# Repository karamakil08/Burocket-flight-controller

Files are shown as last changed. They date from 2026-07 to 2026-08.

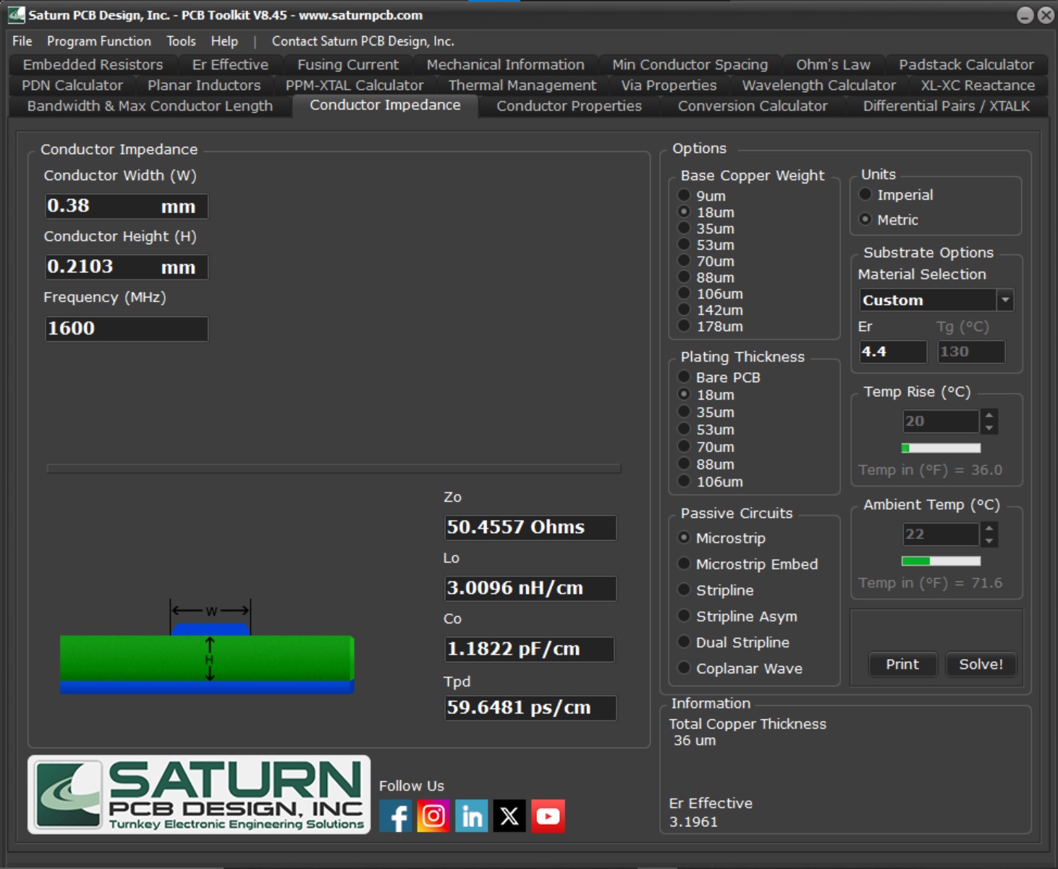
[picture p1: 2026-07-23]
docs/Impedance matching calculations/GPS Mircostrip waveguide 50 ohm impedance.jpg

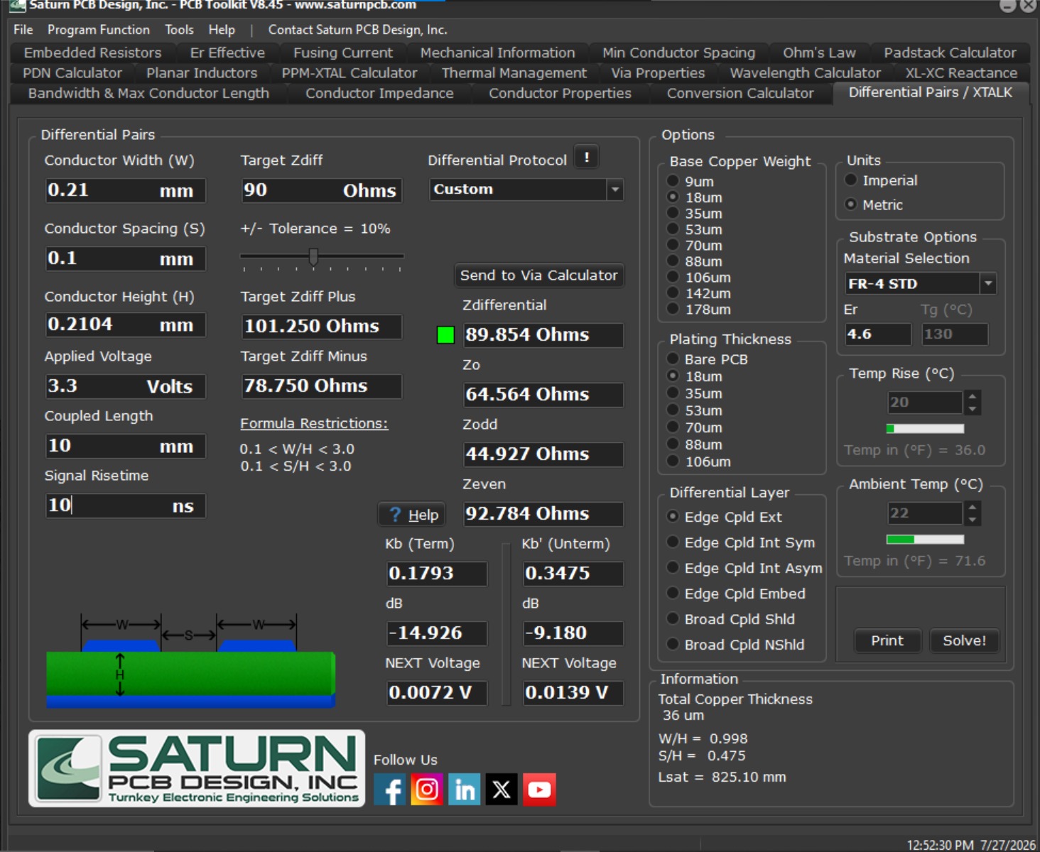
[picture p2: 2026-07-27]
docs/Impedance matching calculations/USB-c Differential pair 90 ohm impedance.jpg

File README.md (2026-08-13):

# Burocket Flight Controller

This is a flight controller built around the STM32F405 MCU for model rocket applications designed to perform altitude, gyro, and acceleration measurements, fire pyrotechnics, and save flight data safely.

## Component Selection

The components selected for this project were chosen according to various measures:
* Application requirement
* Ease of supply
* Price
* Performance
* Footprint area

## Hardware Subsystems

Detailed documentation for each subsystem can be found below:

* [MCU](docs/MCU.md)
* [Sensors](docs/Sensors.md)
* [POWER](docs/POWER.md)
* [Relays](docs/Relays.md)
* [LoRa](docs/LoRa.md)
* [USB-C](docs/USB-C.md)
* [Flash Memory](docs/Flash_memory.md)
* [SD-Card](docs/SD-card.md)

## Pin Distribution & Firmware

You can find the STMCubeMX pin distribution and firmware source files here:
* 🔗 [Firmware Directory](https://github.com/karamakil08/Burocket-flight-controller/tree/main/Firmware)

## Documentation & Resources

* 🔗 [Datasheets](https://github.com/karamakil08/Burocket-flight-controller/tree/main/docs/Datasheets)
* 🔗 [Application Notes](https://github.com/karamakil08/Burocket-flight-controller/tree/main/docs/App%20notes)
* 🔗 [Additional Useful Resources](https://github.com/karamakil08/Burocket-flight-controller/blob/main/docs/App%20notes/Links%20to%20additional%20resources%20I%20found%20useful.md)

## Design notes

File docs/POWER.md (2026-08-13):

# Power Subsystem

The power delivery network is designed to ensure continuous, clean power to all logic and sensor systems, with fail-safes for ground testing and flight operations.

## Power Sources & Multiplexing

The system operates from two primary power sources:
1.  **Flight Battery:** A 2S LiPo battery (nominally 7.4V - 8.4V).
2.  **USB-C VBUS:** 5V provided via the USB interface for ground configuration and data retrieval.

**Buck Conversion & 5V Bus:**
The 2S battery voltage is stepped down to 5V using a dedicated buck converter. This 5V bus is used to power higher-voltage peripherals, including the LoRa telemetry module.

**Power Muxing (TPS2121RUXR):**
To safely manage power when both the battery and USB are connected, the system uses a **TPS2121RUXR** priority power multiplexer. This IC automatically and seamlessly switches between the 5V buck output and the USB-C VBUS. It prevents back-powering into the USB host and eliminates voltage droops or system resets when plugging or unplugging the USB cable on the launch pad.

## 3.3V Regulation

**LDO Regulator:** TPS7A4701
The 5V multiplexed output is stepped down to 3.3V using the **TPS7A4701** Low-Dropout (LDO) regulator. 
*   **Properties:** The TPS7A4701 is an ultra-low-noise ($4.1 \text{ }\mu V_{RMS}$), high-PSRR linear regulator capable of outputting up to 1A. 
*   **Application:** While highly capable, this is an instrumentation-grade regulator. Its extreme noise rejection ensures that the high-resolution ADCs on the MS5611 barometer and ICM IMUs have a perfectly stable voltage reference, minimizing noise floor in the telemetry data.

## Power Monitoring & Current Sensing

To monitor system health, power consumption, and battery state, a high-precision current sensing architecture is implemented on the main power rails.

**Current Sensor:** INA226
The **INA226** is a bidirectional current and power monitor with an I2C interface. It measures both the shunt voltage drop and the bus supply voltage, allowing the flight computer to log real-time power consumption and detect potential shorts or brown-out conditions before they cause a critical failure.

**Shunt Resistor:** WSLP12065L000FEA
*   **Properties:** $5\text{ m}\Omega$, 1% tolerance, 1W rating in a 1206 package.
*   **Performance:** Using a $5\text{ m}\Omega$ shunt with the INA226 (which has a maximum shunt voltage reading of $81.92\text{ mV}$) allows the system to measure current peaks up to $\sim 16.38\text{ A}$ before the ADC saturates ($I = \frac{81.92\text{ mV}}{5\text{ m}\Omega}$). The 1W power rating ensures the resistor can comfortably handle high current spikes (up to $14.1\text{ A}$ continuous) without thermal degradation or desoldering under load.

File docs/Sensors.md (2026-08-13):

# Sensors Subsystem

The sensor suite on this flight controller is designed to provide high-resolution, high-speed telemetry for orientation, altitude detection, and recovery operations. 

## Barometric Pressure & Temperature

**Sensor:** MS5611
The MS5611 is an industry-standard, high-reliability altimeter utilized heavily in aerospace and drone applications. It features a 24-bit ADC providing a resolution of up to 10 cm, which is critical for accurate apogee detection and precise pyrotechnic deployment. It was selected due to its proven track record in flight computers, overall abundance in the supply chain, and ease of integration.

## Inertial Measurement Units (IMU)

**Primary IMU:** ICM-42688-P
The ICM-42688-P is a premium 6-axis MEMS motion tracking device that combines a 3-axis gyroscope and a 3-axis accelerometer. It features exceptionally low noise and high sensitivity, providing the real-time orientation and angular velocity data required for flight stabilization and trajectory tracking. 

**High-G Accelerometer:** ADXL375
Standard IMUs typically saturate at around **16g**, which is easily exceeded during the boost phase or ejection shock of a high-powered model rocket. The ADXL375 is an additional 3-axis accelerometer capable of measuring up to **200g**. This ensures continuous data logging and flight profiling even when the ICM-42688-P's accelerometer is saturated.

**Design Consideration & Alternative:**
Using both the ICM-42688-P and ADXL375 introduces a physical challenge: if the sensor axes are not perfectly aligned on the PCB, a rotation matrix must be applied in software to normalize the data vectors. While solvable in firmware, this adds computational overhead and complexity. 
* *Alternative:* Future revisions may consider the **ICM-45686**, which features a **32g** acceleration limit. Depending on the motor profile, this higher limit might prevent saturation entirely, allowing the removal of the ADXL375 and bypassing the axes alignment complications entirely.

## GPS / GNSS Receiver

**Sensor:** MAX-M10N
The MAX-M10N by u-blox is a highly sensitive, ultra-low-power GNSS receiver module. It tracks multiple constellations concurrently (GPS, Galileo, GLONASS, and BeiDou), providing rapid lock times and high positional accuracy. This is the primary system utilized for post-flight ground tracking and rocket recovery.

## SPI Bus Signal Integrity & Safety

Communication with the primary sensors is handled via the SPI bus, which has been designed with strict signal integrity and fail-safes in mind:

* **Series Termination Resistors:** High-speed SPI lines are susceptible to ringing and voltage overshoots. Series resistors are placed on the bus lines to match the impedance of the traces. To function correctly, these resistors are placed as physically close to the driving device as possible (near the MCU for MOSI and SCK; near the sensors for MISO).
* **Slave Select (SS) Pull-Ups:** Dedicated pull-up resistors are integrated on all SS lines. This hardware-level safeguard keeps the pins at a logical HIGH state during system startup, resets, or when the MCU is unconfigured. This guarantees that the peripheral chips do not accidentally activate, listen to floating lines, or corrupt the shared bus before the firmware actively takes control.

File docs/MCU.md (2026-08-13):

# MCU Subsystem

## Clock Configuration

The system is driven by a 25 MHz High-Speed External (HSE) oscillator. A series damping resistor is often recommended to limit the crystal drive level, but it was deemed non-mandatory and excluded from this design.

The load capacitors for the oscillator were calculated using the standard formula:

$$C_1 = C_2 = 2 \times (C_L - C_S)$$

Where:
*   **$C_L$ (Load Capacitance):** 10 pF (based on the [ECS-250-10-36Q-ES-TR](https://www.mouser.com/ProductDetail/ECS/ECS-250-10-36Q-ES-TR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) specification)
*   **$C_S$ (Stray Capacitance):** Estimated at 5 pF for this PCB layout

$$C_1 = C_2 = 2 \times (10\text{ pF} - 5\text{ pF}) = 10\text{ pF}$$

Based on this calculation, 10 pF capacitors were selected for both $C_1$ and $C_2$.

## User Interface & Controls

*   **Status Indicators:** The board features two indicator LEDs (one Red, one Blue) for system state feedback.
*   **Hardware Reset:** A dedicated push button is routed to the NRST pin to allow manual system resets.
*   **Boot Configuration:** An SPDT (Single Pole Double Throw) switch is connected to the BOOT pin, allowing the user to physically toggle between boot modes.

## Power & Debugging

*   **Decoupling:** Power delivery is stabilized across the MCU utilizing X7R dielectric capacitors, selected for their high performance and temperature stability in flight environments.
*   **Programming Interface:** A Serial Wire Debug (SWD) interface is exposed for programming and debugging. This interface includes a Serial Wire Output (SWO) pin connection to enable real-time trace logging.

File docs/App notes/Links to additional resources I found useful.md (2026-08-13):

# Useful Technical References & Resources

## STM32 Configuration
- Configuring a pin as open-drain output with EXTI:  
  [STM32 Community Thread](https://community.st.com/stm32-mcus-products-25/pin-as-an-open-drain-output-and-exti-at-the-same-time-stm32f030-58373)

## Passive Component Selection Tools
- **Samsung Capacitor Library**:  
  [MLCC & EC Tool](https://weblib.samsungsem.com/mlcc/mlcc-ec.do)  
- **Murata Passive Components**:  
  [SimSurfing Tool](https://www.murata.com/tool/simsurfing)

## Ferrite Beads
- [Short Overview](https://shorturl.at/rvSlJ)  
- [Video: How Ferrite Beads Work](https://www.youtube.com/watch?v=HaLMjVkKYMw)  
- [Altium: Everything You Need to Know](https://resources.altium.com/p/everything-you-need-to-know-about-ferrite-beads)  
- [Altium: How to Choose the Right One](https://resources.altium.com/p/how-do-ferrite-beads-work-and-how-do-you-choose-right-one)  
- [Altium: Three Frequency Ranges for Usage](https://resources.altium.com/p/three-frequency-ranges-ferrite-bead-usage)

## Buck Converters
- [Switching Regulator PCB Design - Phil's Lab](https://www.youtube.com/watch?v=AmfLhT5SntE)  
- [Switching Regulator Component Selection & Sizing - Phil's Lab](https://www.youtube.com/watch?v=FqT_Ofd54fo)  
- [Switching Power Supply PCB Layout Seminar](https://www.youtube.com/watch?v=gq-0ZpcGm8E)  
- [How to Select the Right Inductor for a Buck Converter](https://www.youtube.com/watch?v=ro_ZoAuNZG4)  
- [TI Webench Power Designer](https://webench.ti.com/power-designer/)

## Differential Pairs (USB)
- [Differential Pairs - PCB Design Basics - Phil's Lab](https://www.youtube.com/watch?v=xwrdvhm4vgw)  
- [What your Differential Pairs Wish You Knew with Rick Hartley](https://www.youtube.com/watch?v=QG0Apol-oj0)

## Controlled Impedance
- [Controlled Impedance Explained](https://www.youtube.com/watch?v=aNYmOIMt7CY)

## ESD Protection
- [ESD Protection Fundamentals](https://www.youtube.com/watch?v=MmG_m4xVNfQ)

## SD Cards
- [How to Use MMC/SDC](https://elm-chan.org/docs/mmc/mmc_e.html)

## High-Speed Digital Design
- [Analog Devices MT-097 Tutorial (PDF)](https://www.analog.com/media/en/training-seminars/tutorials/mt-097.pdf)

## Optocouplers
- [Broadcom Application Note AV02-4387EN](https://docs.broadcom.com/doc/AV02-4387EN)  
- [Vishay EDN Design Note](https://www.vishay.com/docs/48034/edn0715.pdf)

## Some exquisite Music
- [Track 1](https://www.youtube.com/watch?v=yEN5rGR7gtM)  
- [Track 2 (Radio)](https://www.youtube.com/watch?v=X-jdl9hcCeg&list=RDX-jdl9hcCeg&start_radio=1)  
- [Track 3](https://youtu.be/WGw4mn2-ILc?si=stj307PhLHUFaAwW)

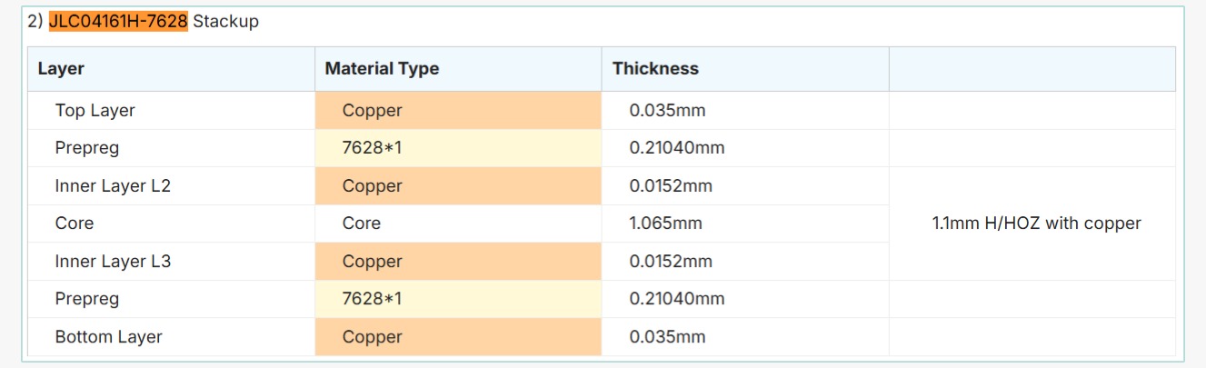
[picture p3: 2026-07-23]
docs/Impedance matching calculations/JLC04161H-7628 stack-up properties.jpg

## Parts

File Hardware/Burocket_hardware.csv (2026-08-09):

Reference | Value | Datasheet | Footprint | Qty | DNP | Distributer Link | Part Number
BZ1 | Buzzer | https://klsele.com/products/Sound-sources/SMT-Magnetic-Buzzers/8573.html | footprints:Buzzer_typeshit | 1 |  | https://www.ozdisan.com/p/buzzerlar-430/kls-electronic-l-kls3-smt-3020-3v-744329?s=KLS3-SMT-3020 | L-KLS3-SMT-3020-3V
C11,C15,C17,C19,C21,C22,C23,C24,C25,C26,C28,C29,C30,C31,C32,C33,C36,C37,C38,C39,C40,C41,C42,C43,C44,C51,C56,C58,C59,C60 | 100nF | https://cdn.ozdisan.com/public/product/assets/SAMSUNG_MLCC_Automotive_JAN-2024.pdf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 | Capacitor_SMD:C_0603_1608Metric | 30 |  | https://www.ozdisan.com/p/smt-smd-ve-mlcc-kapasitorler-184/samsung-cl10b104ko8wpnc-522227 | CL10B104KO8WPNC
C12,C13,C14,C16,C20,C27,C35,C47,C54,C55 | 2.2uF | https://cdn.ozdisan.com/public/product/assets/SAMSUNG%20MLCC_JAN-2024.pdf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 | Capacitor_SMD:C_0603_1608Metric | 10 |  | https://www.ozdisan.com/p/smt-smd-ve-mlcc-kapasitorler-184/samsung-cl10b225kp8nnnc-359581 | CL10B225KP8NNNC
C18,C61 | 10pF | https://cdn.ozdisan.com/public/product/assets/SAMSUNG_MLCC_Automotive_JAN-2024.pdf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 | Capacitor_SMD:C_0603_1608Metric | 2 |  | https://www.ozdisan.com/p/smt-smd-ve-mlcc-kapasitorler-184/samsung-cl10c100jb81pnc-522432 | CL10C100JB81PNC
C34,C49,C50 | 100uF | https://cdn.ozdisan.com/public/product/assets/VISHAY-293D%20SERIES.pdf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 | Capacitor_Tantalum_SMD:CP_EIA-6032-20_AVX-F | 3 |  | https://www.ozdisan.com/p/tantal-kapasitorler-178/vishay-293d107x0010c2te3-502187 | 293D107X0010C2TE3
C45,C46,C48,C52,C53,C57,C62 | 22uF | https://cdn.ozdisan.com/public/product/assets/SAMSUNG%20MLCC_JAN-2024.pdf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 | Capacitor_SMD:C_0805_2012Metric | 7 |  | https://www.ozdisan.com/p/smt-smd-ve-mlcc-kapasitorler-184/samsung-cl21a226koqnnne-399002 | CL21A226KOQNNNE
C64,C69,C70 | 47uF | https://cdn.ozdisan.com/public/product/assets/SAMSUNG%20MLCC_JAN-2024.pdf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 | Capacitor_SMD:C_1210_3225Metric | 3 |  | https://www.ozdisan.com/p/smt-smd-ve-mlcc-kapasitorler-184/samsung-cl32a476kojnnne-423179 | CL32A476KOJNNNE
C65,C66 | 47pF | https://cdn.ozdisan.com/public/product/assets/SAMSUNG_MLCC_Automotive_JAN-2024.pdf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 | Capacitor_SMD:C_0603_1608Metric | 2 |  | https://www.ozdisan.com/p/smt-smd-ve-mlcc-kapasitorler-184/samsung-cl10c470jb81pnc-522565 | CL10C470JB81PNC
D1 | Blue_LED | https://cdn.ozdisan.com/public/product/assets/HL-PST-1608H203BC-yeni.PDF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 | Capacitor_SMD:C_0603_1608Metric | 1 |  | https://www.ozdisan.com/p/sinyal-ledler-tek-renkli-361/honglitronic-hl-pst-1608h203bc-471659 | HL-PST-1608H203BC
D2,D8 | Red LED | https://cdn.ozdisan.com/public/product/assets/27-21-R6C-AP1Q2B-3C.PDF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 | Capacitor_SMD:C_0603_1608Metric | 2 |  | https://www.ozdisan.com/p/sinyal-ledler-tek-renkli-361/everlight-27-21-r6c-ap1q2b-3c-602569 | 27-21/R6C-AP1Q2B/3C
D3 | ESD321DYAR | https://www.onsemi.com/pdf/datasheet/esd5z2.5t1-d.pdf | Diode_SMD:D_SOD-523 | 1 |  | https://www.mouser.com.tr/en/ProductDetail/Texas-Instruments/ESD321DYAR?qs=rQFj71Wb1eXoYwRMra0IYA%3D%3D | ESD321DYAR
D4 | Green LED | https://cdn.ozdisan.com/public/product/assets/HL-PST-1608U51GC-yeni.PDF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 | LED_SMD:LED_0603_1608Metric | 1 |  | https://www.ozdisan.com/p/sinyal-ledler-tek-renkli-361/honglitronic-hl-pst-1608u51gc-471660 | HL-PST-1608U51GC
D5 | 1N4448W | https://cdn.ozdisan.com/public/product/assets/1N4448W_PANJIT.pdf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 | Diode_SMD:Nexperia_CFP3_SOD-123W | 1 |  | https://www.ozdisan.com/p/dogrultucu-diyotlar-389/panjit-1n4448w-r1-00001-584183 | 1N4448W_R1_00001
D6,D7 | 1N4148W | https://cdn.ozdisan.com/public/product/assets/1N4148W-AU_PANJIT.pdf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 | Diode_SMD:D_SOD-123 | 2 |  | https://www.ozdisan.com/p/dogrultucu-diyotlar-389/panjit-1n4148w-au-r1-000a1-707988 | 1N4148W-AU_R1_000A1
FB1 | FerriteBead | https://www.murata.com/en-us/products/productdata/8796741599262/ENFA0004.pdf | Resistor_SMD:R_0603_1608Metric | 1 |  | https://www.mouser.com.tr/en/ProductDetail/Murata-Electronics/BLM18HE601SN1D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 | BLM18HE601SN1D
J1 | USB4105-GF-A-120 | https://cdn.ozdisan.com/public/product/assets/usb4105.pdf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 | USB4105-GF-A-120:GCT_USB4105-GF-A-120 | 1 |  | https://www.mouser.com.tr/en/ProductDetail/GCT/USB4105-GF-A-120?qs=QNEnbhJQKva%252Bjxw%2FpEjDhQ%3D%3D | USB4105-GF-A-120
J3 | SD-card | https://www.molex.com/en-us/products/part-detail-pdf/1040310811?display=pdf | Molex 1040310811:104031-0811_MOL | 1 |  | https://www.mouser.com.tr/en/ProductDetail/Molex/104031-0811?qs=udsGRKD4nA3Tvy7wqky%252BuA%3D%3D | MOLEX-1040310811
L3 | 6.8uH | https://www.we-online.com/components/products/datasheet/74439346068.pdf | Inductor_SMD:L_Wuerth_XHMI-6060 | 1 |  | https://www.mouser.com.tr/en/ProductDetail/Wurth-Elektronik/74439346068?qs=NSAOzM2zc%2FVj5BeHYKNgfQ%3D%3D | 74439346068
Q1 | BC847 | https://cdn.ozdisan.com/public/product/assets/ONS_BC846AWT1-D.PDF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 | Package_TO_SOT_SMD:SOT-323_SC-70 | 1 |  | https://www.e-komponent.com/bc817-40w-r1-00001-panjit-international-bipolar-transistor-tekli | BC817-40W_R1_00001
Q6,Q8,Q9,Q11 | IRLML0030 | https://www.infineon.com/dgdl/irlml0030pbf.pdf?fileId=5546d462533600a401535664773825df | Package_TO_SOT_SMD:SOT-23 | 4 |  | https://www.mouser.com.tr/en/ProductDetail/Infineon-Technologies/IRLML0030TRPBF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 | IRLML0030TRPBF
Q7 | BCR116 | https://www.mouser.com/datasheet/2/196/Infineon-BCR116SERIES-DS-v01_01-en-514457.pdf | Package_TO_SOT_SMD:SOT-23-3 | 1 |  | https://www.e-komponent.com/bcr116e6327htsa1-infineon-on-gerilimli-bipolar-transistor-tekli | BCR116E6327HTSA1
R4,R5 | 4.7k ? | https://cdn.ozdisan.com/public/product/assets/AECQ200CQ_ROYALOHM.pdf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 | Resistor_SMD:R_0603_1608Metric | 2 |  | https://www.ozdisan.com/p/smt-smd-ve-cip-direncler-194/royalohm-cq03saj0472t5e-587928 | CQ03SAJ0472T5E
R7,R8 | 5.1k ? | https://www.mouser.com.tr/datasheet/3/40/1/cr.pdf | Resistor_SMD:R_0603_1608Metric | 2 |  | https://www.mouser.com.tr/en/ProductDetail/Bourns/CR0603-FX-5101ELF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 | CR0603-FX-5101ELF
R10,R11,R12,R13,R15 | 1k ? | https://cdn.ozdisan.com/public/product/assets/Data%20Sheet%20CRCW_BCe3.pdf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 | Resistor_SMD:R_0603_1608Metric | 5 |  | https://www.ozdisan.com/p/smt-smd-ve-cip-direncler-194/vishay-crcw06031k00jntabc-358937 | CRCW06031K00JNTABC
R27,R68,R69,R70,R71,R72,R73,R74,R101,R102,R103,R104,R105,R106,R107,R108 | 22 ? | https://cdn.ozdisan.com/public/product/assets/AECQ200CQ_ROYALOHM.pdf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 | Resistor_SMD:R_0603_1608Metric | 16 |  | https://www.ozdisan.com/p/smt-smd-ve-cip-direncler-194/panasoniceurope-erjpa3j220v-1189964 | CQ03SAJ0220T5E,ERJPA3J220V
R28,R33,R35,R36,R37,R38 | 4.7 ? | https://cdn.ozdisan.com/public/product/assets/AECQ200CQ_ROYALOHM.pdf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 | Resistor_SMD:R_0603_1608Metric | 6 |  | https://www.ozdisan.com/p/smt-smd-ve-cip-direncler-194/royalohm-cq03saf470kt5e-587940 | CQ03SAF470KT5E
R29,R30,R31 | 48.7K ? | https://cdn.ozdisan.com/public/product/assets/general_royalohm.pdf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 | Resistor_SMD:R_0603_1608Metric | 3 |  | https://www.ozdisan.com/p/smt-smd-ve-cip-direncler-194/royalohm-0603saf4872t5e-514500 | 0603SAF4872T5E
R32,R40,R41,R43,R44,R46 | 28k ? | vishay.com/doc?28705 | Resistor_SMD:R_0603_1608Metric | 6 |  | https://www.mouser.com.tr/en/ProductDetail/Vishay-Beyschlag/MCT06030C2802FP500?qs=hjSuqQECij8jE6Kw0BZ0wA%3D%3D | MCT06030C2802FP500
R45,R47,R48,R49 | 300 ? | https://cdn.ozdisan.com/public/product/assets/Pansonic_Anti-Sulfurated%20Thick%20Film%20Chip%20Resistors_ERJ-S%2CS02%2CS03%2CS06%2CS08%2CS14%2CS12%2CS1D%2CS1T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 | Resistor_SMD:R_0603_1608Metric | 4 |  | https://www.ozdisan.com/p/smt-smd-ve-cip-direncler-194/panasoniceurope-erj3ekf3000v-614721?catSequenceId=194 | ERJ3EKF3000V
R53,R55,R56,R60,R61,R62,R75,R77,R81,R85,R86,R87,R88,R89,R90,R91,R92,R93,R94,R95,R96,R97,R98,R99,R100 | 10k ? | https://cdn.ozdisan.com/public/product/assets/ThinFilmTC_ROYALOHM_REV.pdf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 | Resistor_SMD:R_0603_1608Metric | 25 |  | https://www.ozdisan.com/p/smt-smd-ve-cip-direncler-194/royalohm-tc0350b1002t5f-700101,https://www.ozdisan.com/p/smt-smd-ve-cip-direncler-194/viking-crt03j7e10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 | CRT03J7E1002,TC0350B1002T5F
R76 | 53k6 ? | https://www.mouser.com.tr/datasheet/3/72/1/PYU_RT_1_TO_0_01_ROHS_L.pdf | Resistor_SMD:R_0603_1608Metric | 1 |  | https://www.mouser.com.tr/en/ProductDetail/YAGEO/RT0603BRD0753K6L?qs=gY0y7AQI9SNAby5h%2F1y0lQ%3D%3D | RT0603BRD0753K6L
R78 | 200k ? | https://cdn.ozdisan.com/public/product/assets/ThinFilmTC_ROYALOHM_REV.pdf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 | Resistor_SMD:R_0603_1608Metric | 1 |  | https://www.ozdisan.com/p/smt-smd-ve-cip-direncler-194/royalohm-tc0325b2003t5c-418932 | TC0325B2003T5C
R79 | 44.2k ? | https://www.mouser.com.tr/en/ProductDetail/YAGEO/RT0603FRE0744K2L?qs=4CyHz7GXqSgyo9YOc1MhMQ%3D%3D | Resistor_SMD:R_0603_1608Metric | 1 |  | https://www.mouser.com.tr/en/ProductDetail/YAGEO/RT0603FRE0744K2L?qs=4CyHz7GXqSgyo9YOc1MhMQ%3D%3D | RT0603FRE0744K2L
R_Shunt1 | 5m ? | https://www.mouser.com.tr/en/ProductDetail/Vishay-Dale/WSLP12065L000FEA?qs=eFWhpKjIuGhd%2FhmgEVginw%3D%3D | Resistor_SMD:R_1206_3216Metric | 1 |  | http://mouser.com.tr/en/ProductDetail/Vishay-Dale/WSLP12065L000FEA?qs=eFWhpKjIuGhd%2FhmgEVginw%3D%3D | WSLP12065L000FEA
SW1 | SW_Push | https://cdn.ozdisan.com/public/product/assets/PTS815-seri-CK.pdf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 | Button_Switch_SMD:SW_SPST_PTS810 | 1 |  | https://www.mouser.com.tr/en/ProductDetail/CK/PTS815SJK250SMTR-LFS?qs=Imq1NPwxi766c6FNPaxxTg%3D%3D | PTS815SJK250SMTRLFS
SW2 | SW_SPDT | https://cdn.ozdisan.com/public/product/assets/L-KLS7-MSK-12C03.pdf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 | Button_Switch_SMD:SW_SPDT_CK_JS102011SAQN | 1 |  | https://www.ozdisan.com/p/surgulu-sivicler-495/kls-electronic-l-kls7-msk-12c03-518011 | L-KLS7-MSK-12C03
U1 | STM32F405RGT6 | https://www.st.com/resource/en/datasheet/stm32f405rg.pdf | Package_QFP:LQFP-64_10x10mm_P0.5mm | 1 |  | https://www.mouser.com.tr/en/ProductDetail/STMicroelectronics/STM32F405RGT6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 | STM32F405RGT6
U4 | TPD2EUSB30DRTR | http://www.ti.com/lit/ds/symlink/tpd2eusb30a.pdf | Package_TO_SOT_SMD:Texas_DRT-3 | 1 |  | https://www.mouser.com.tr/en/ProductDetail/Texas-Instruments/TPD2EUSB30DRTR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 | TPD2EUSB30DRTR
U5 | MS5611-01BA | https://www.te.com/commerce/DocumentDelivery/DDEController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 | MS5611:SON8_MS5611_TEC | 1 |  | https://eu.mouser.com/en/ProductDetail/TE-Connectivity-Measurement-Specialties/MS561101BA03-50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 | MS561101BA03-50
U6 | ICM-42688-P | https://product.tdk.com/system/files/dam/doc/product/sensor/mortion-inertial/imu/data_sheet/ds-000347-icm-42688-p-v1.6.pdf | ICM_42688_P:LGA14_2P5X3X0P91_TDK | 1 |  | https://eu.mouser.com/en/ProductDetail/TDK-InvenSense/ICM-42688-P?qs=OlC7AqGiEDk8QrNAV728zw%3D%3D | ICM-42688-P
U7 | ADXL375 | https://www.analog.com/media/en/technical-documentation/data-sheets/ADXL375-EP.pdf | ADXL375BCCZ_RL7:LGA_CC-14-1_ADI-L | 1 |  | https://eu.mouser.com/en/ProductDetail/Analog-Devices/ADXL375BCCZ-RL7?qs=S4ILP0tmc7QIv%2F7Dk2oBJA%3D%3D | ADXL375BCCZ-RL7
U8 | TPS2121RUXR | https://www.ti.com/lit/gpn/tps2121 | footprints.ugly:RUX0012A | 1 |  | https://www.e-komponent.com/or-controller-source-selector-switch-n-channel | TPS2121RUXR
U9 | MAX-M10N | https://content.u-blox.com/sites/default/files/documents/MAX-M10N-00B_DataSheet_UBXDOC-963802114-13143.pdf | RF_GPS:ublox_MAX | 1 |  | https://www.mouser.com.tr/en/ProductDetail/u-blox/MAX-M10S-00B?qs=A6eO%252BMLsxmT0PfQYPb7LLQ%3D%3D | MAX-M10N-00B
U10 | INA226 | http://www.ti.com/lit/ds/symlink/ina226.pdf | Package_SO:TSSOP-10_3x3mm_P0.5mm | 1 |  | https://www.ozdisan.com/p/akim-yonetimi-entegreleri-273/texas-ina226aidgsr-640350 | INA226AIDGSR
U11 | W25Q128JVS | https://www.winbond.com/resource-files/w25q128jv_dtr%20revc%2003272018%20plus.pdf | Package_SO:SOIC-8_5.3x5.3mm_P1.27mm | 1 |  | https://www.ozdisan.com/en/p/embedded-memories-255/winbond-w25q128jvsiq-525521 | W25Q128JVSIQ
U12 | TPS7A4701 | https://www.ti.com/lit/ds/symlink/tps7a47.pdf?ts=1784698731551 | Package_DFN_QFN:Texas_RGW0020A_VQFN-20-1EP_5x5mm_P0.65mm_EP3.15x3.15mm | 1 |  | https://www.mouser.com.tr/en/ProductDetail/Texas-Instruments/TPS7A4701RGWT?qs=2YfbMANv380lIzdxzN9K4Q%3D%3D | TPS7A4701RGWT
U14 | TPS62933 | https://www.ti.com/lit/ds/symlink/tps62933.pdf | Package_TO_SOT_SMD:SOT-583-8 | 1 |  | https://www.mouser.com.tr/en/ProductDetail/Texas-Instruments/TPS62933DRLR?qs=Rp5uXu7WBW9fv47wfQVntQ%3D%3D | TPS62933DRLR
Y2 | 25MHz | https://cdn.ozdisan.com/public/product/assets/ECS_ECX-2236Q.pdf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 | Crystal:Crystal_SMD_2520-4Pin_2.5x2.0mm | 1 |  | https://www.ozdisan.com/p/kristaller-508/ecs-ecs-250-10-36q-es-tr-710745 | ECS-250-10-36Q-ES-TR

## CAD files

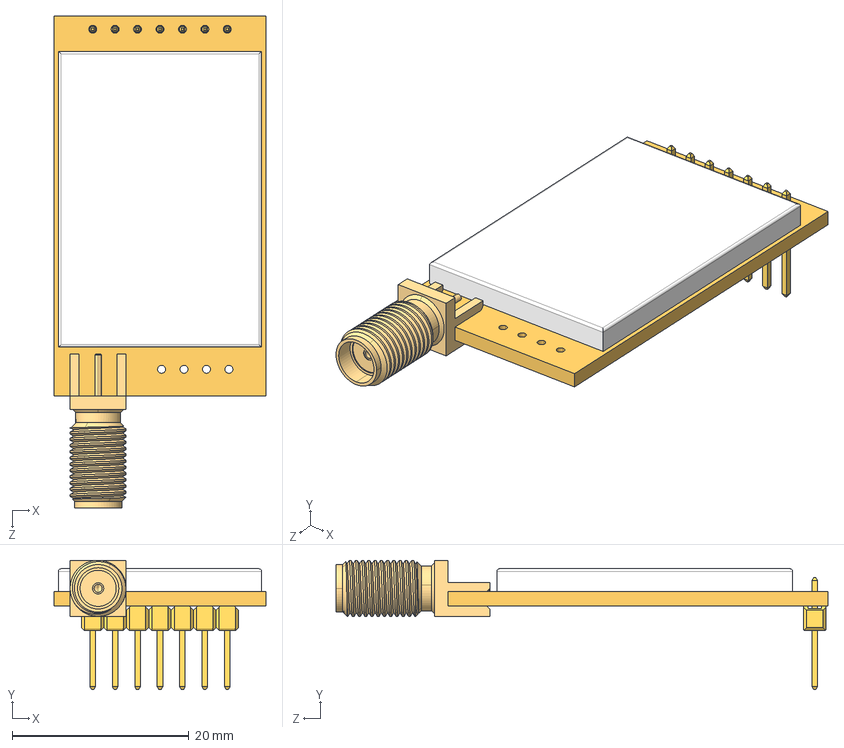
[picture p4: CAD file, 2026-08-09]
Hardware/3D Models and footprints/3D Models/E32-868T30D_Assembly_with_UART_Header.STEP
24.0 x 14.7 x 55.7 mm
Board_Varsay考an
SMA-K Connector_Varsay考an
Pin Header 1x7 TH Pitch 2.54mm.stp_Varsay考an

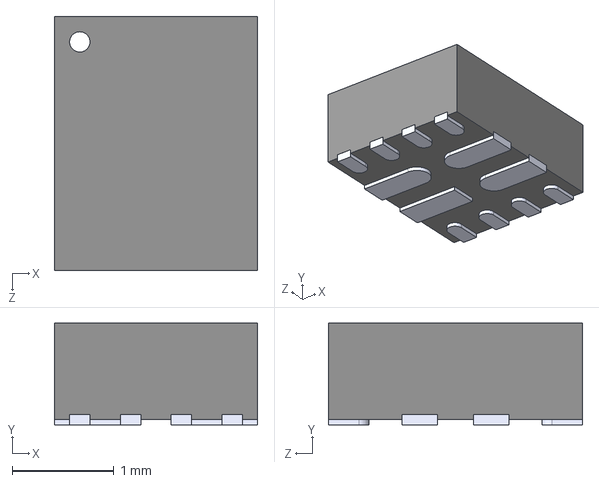
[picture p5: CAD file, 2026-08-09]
Hardware/3D Models and footprints/3D Models/TPS2121RUXR.STEP
2.00 x 1.00 x 2.50 mm

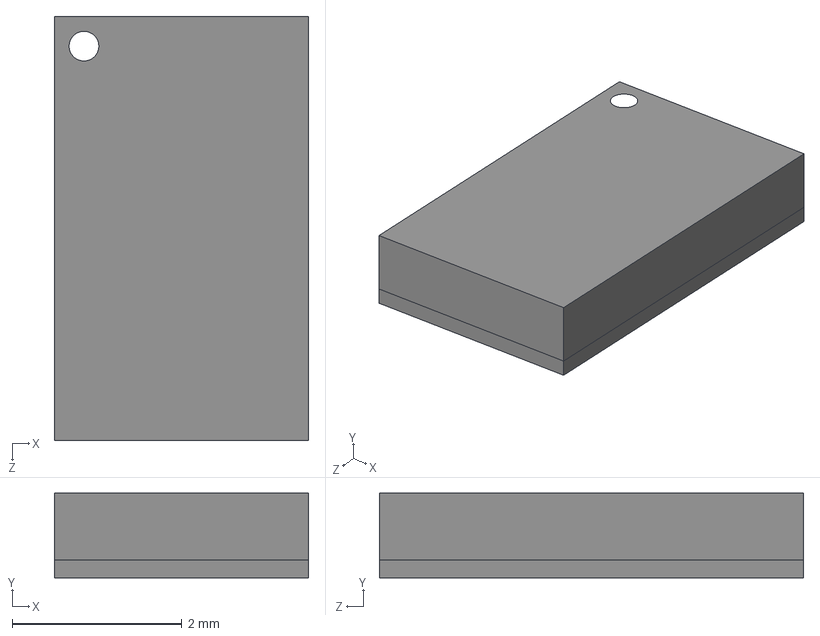
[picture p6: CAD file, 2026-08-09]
Hardware/3D Models and footprints/3D Models/ADXL375BCCZ-RL.STEP
3.00 x 1.00 x 5.00 mm

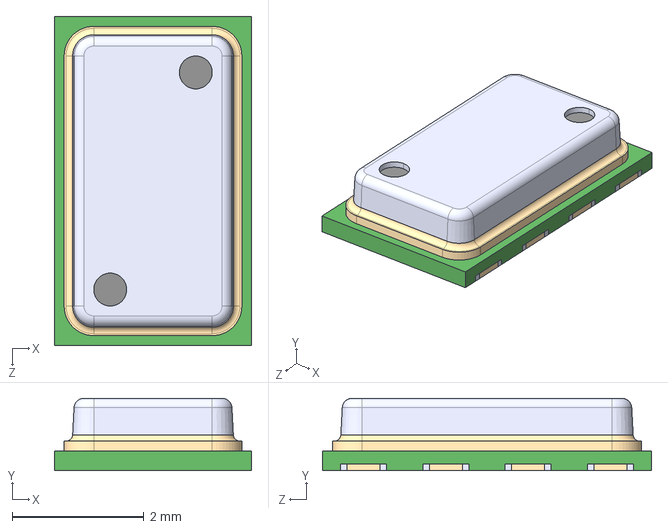
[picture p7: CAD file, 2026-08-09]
Hardware/3D Models and footprints/3D Models/MS5611-01BA03.STEP
3.00 x 1.10 x 5.00 mm

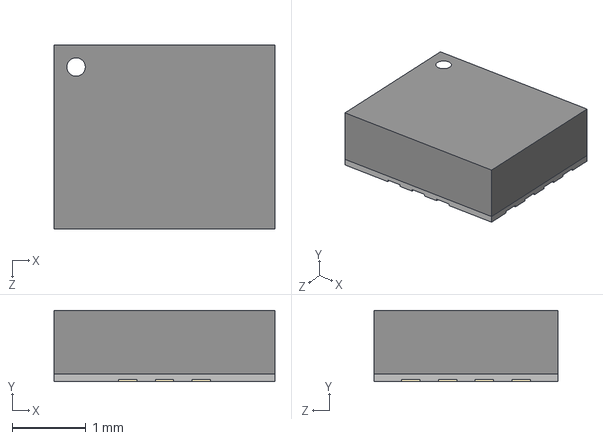
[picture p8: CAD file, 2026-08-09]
Hardware/3D Models and footprints/3D Models/ICM-42688-P.STEP
3.00 x 0.97 x 2.50 mm

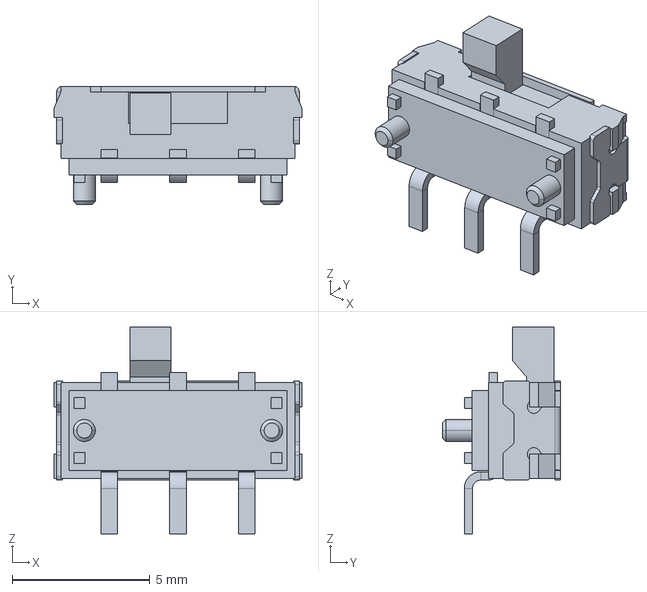
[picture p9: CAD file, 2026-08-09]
Hardware/3D Models and footprints/3D Models/SPDT switch.STEP
9.00 x 4.30 x 7.50 mm

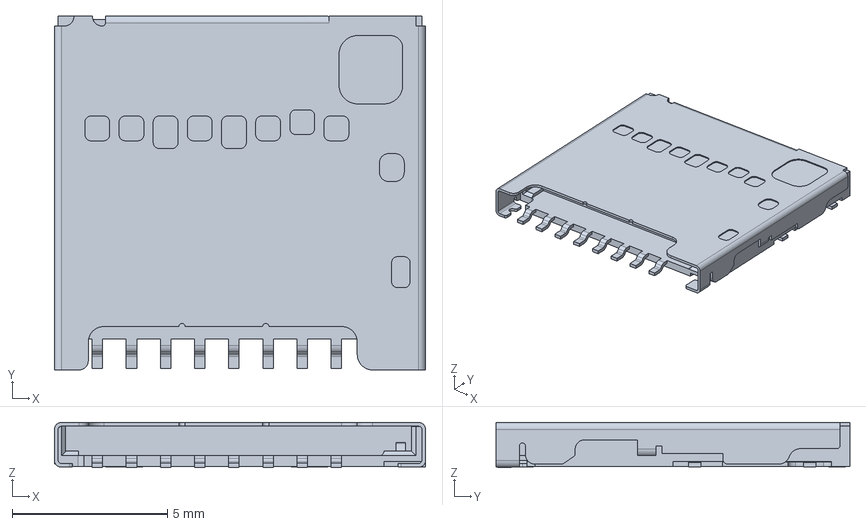
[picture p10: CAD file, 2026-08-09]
Hardware/3D Models and footprints/3D Models/SD-card socket.stp
11.9 x 11.4 x 1.45 mm

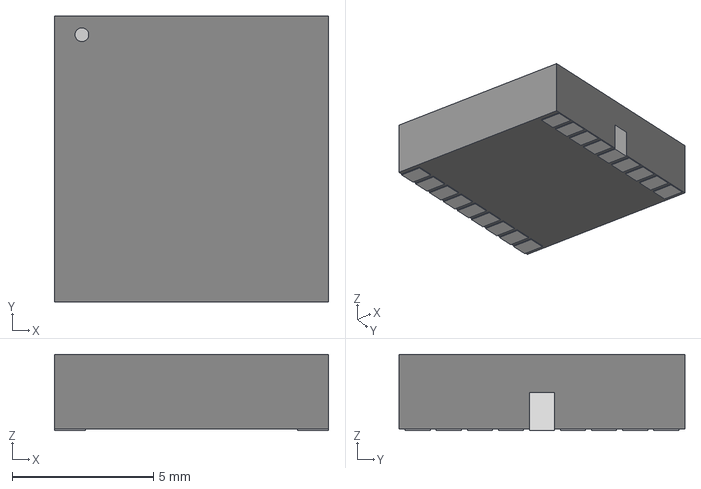
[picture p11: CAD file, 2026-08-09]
Hardware/3D Models and footprints/3D Models/MAX-M10N_00B.step
9.70 x 10.1 x 2.69 mm

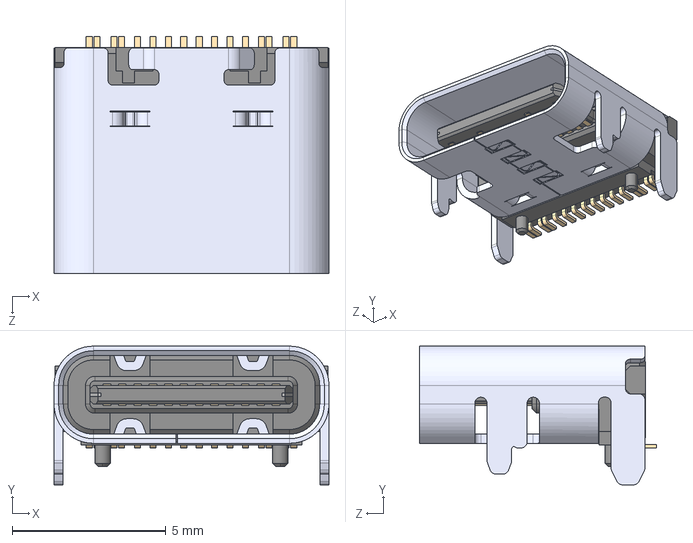
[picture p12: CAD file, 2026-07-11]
Hardware/3D Models and footprints/3D Models/USB4105-GF-A-120.step
8.94 x 4.51 x 7.71 mm

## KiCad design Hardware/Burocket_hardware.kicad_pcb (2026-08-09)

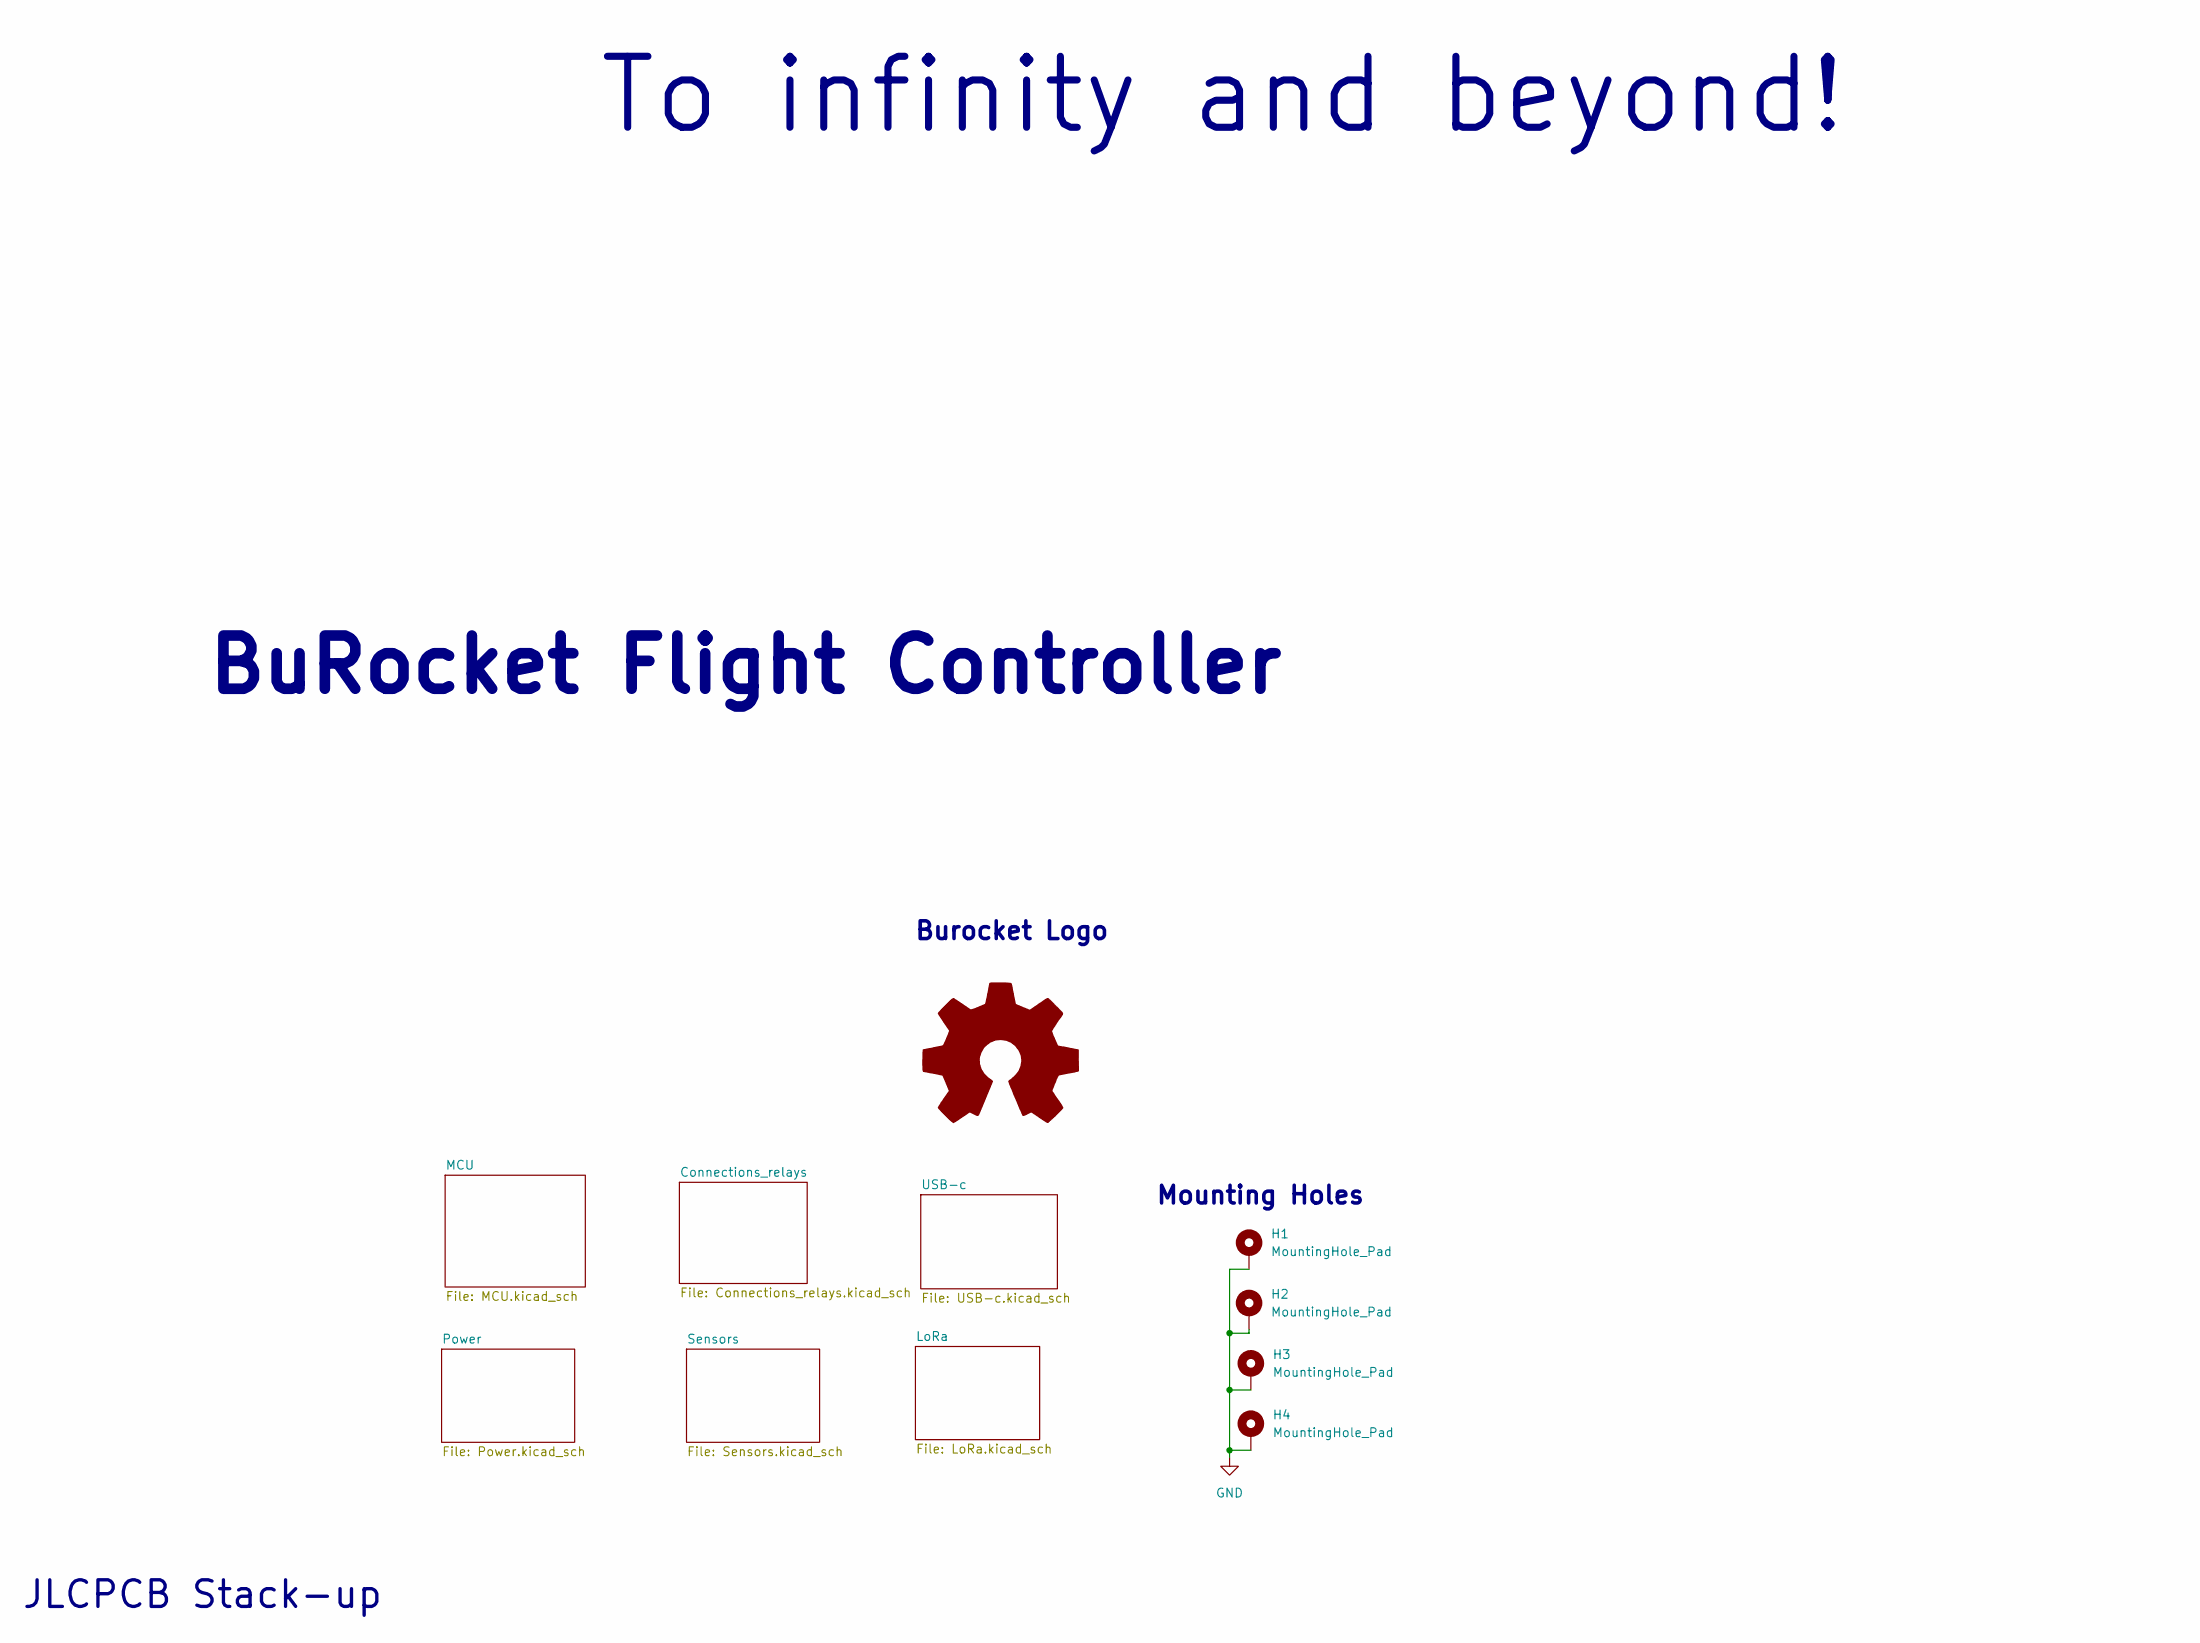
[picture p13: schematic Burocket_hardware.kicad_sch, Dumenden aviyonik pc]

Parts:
H1, H2, H3, H4: MountingHole_Pad; MountingHole_2.2mm_M2_Pad_Via
Logo1: Burocket Logo

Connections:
GND: H1.1 (1_1), H2.1 (1_1), H3.1 (1_1), H4.1 (1_1); also elsewhere on the board

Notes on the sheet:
Burocket Logo
BuRocket Flight Controller
JLCPCB Stack-up
Mounting Holes
To infinity and beyond!

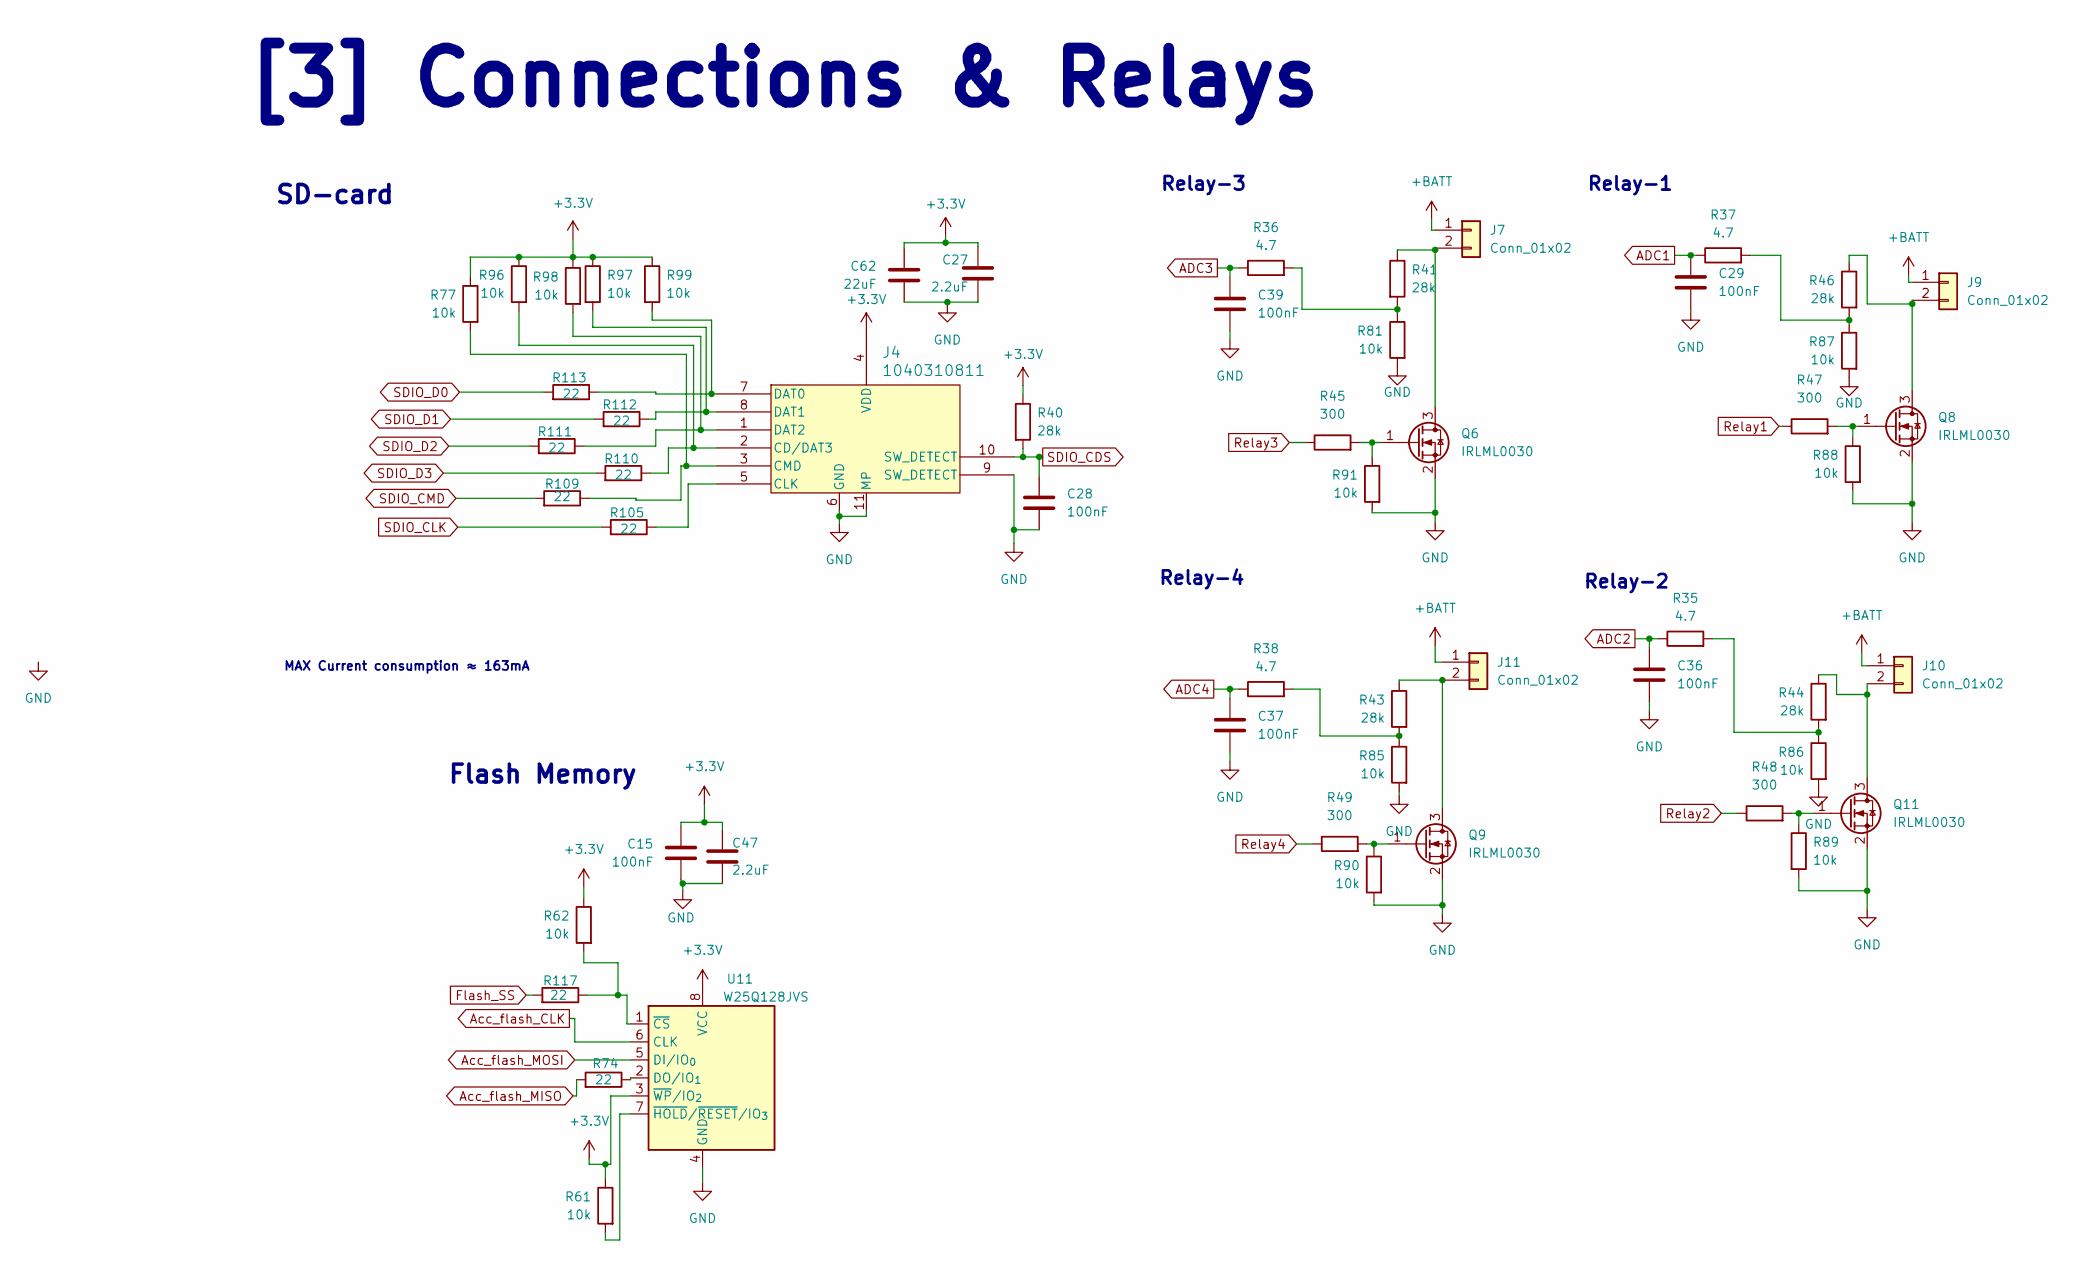
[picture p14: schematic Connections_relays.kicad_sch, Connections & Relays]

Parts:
C15, C28, C29, C36, C37, C39: 100nF; C_0603_1608Metric; Part Number CL10B104KO8WPNC
C27, C47: 2.2uF; C_0603_1608Metric; Part Number CL10B225KP8NNNC
C62: 22uF; C_0805_2012Metric; Part Number CL21A226KOQNNNE
J4: 1040310811; 104031-0811_MOL
J7, J9, J10, J11: Conn_01x02; E-match_Solder
Q6, Q8, Q9, Q11: IRLML0030; SOT-23
R35, R36, R37, R38: 4.7; R_0603_1608Metric; Part Number CQ03SAF470KT5E
R40, R41, R43, R44, R46: 28k; R_0603_1608Metric; Part Number MCT06030C2802FP500
R45, R47, R48, R49: 300; R_0603_1608Metric; Part Number ERJ3EKF3000V
R61, R62, R77, R88, R89, R90, R91, R96, R97, R98, R99: 10k; R_0603_1608Metric; Part Number CRT03J7E1002
R74, R105, R109, R110, R111, R112, R113, R117: 22; R_0603_1608Metric; Part Number CQ03SAJ0220T5E
R81, R85, R86, R87: 10k; R_0603_1608Metric; Part Number TC0350B1002T5F
U11: W25Q128JVS; SOIC-8_5.3x5.3mm_P1.27mm; Part Number W25Q128JVSIQ

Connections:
+3.3V: C15.1, C27.1, C47.1, C62.1, J4.4 (VDD), R40.1, R61.1, R62.1, R77.1, R96.1, R97.1, R98.1, R99.1, U11.3 (~WP/IO_{2}), U11.8 (VCC); also elsewhere on the board
+BATT: J7.1, J9.1, J10.1, J11.1; also elsewhere on the board
ADC1: C29.1, R37.1; also elsewhere on the board
ADC2: C36.1, R35.1; also elsewhere on the board
ADC3: C39.1, R36.1; also elsewhere on the board
ADC4: C37.1, R38.1; also elsewhere on the board
Acc_flash_CLK: U11.6 (CLK); also elsewhere on the board
Acc_flash_MOSI: U11.5 (DI/IO_{0}); also elsewhere on the board
Flash_SS: R117.2; also elsewhere on the board
GND: C15.2, C27.2, C28.2, C29.2, C36.2, C37.2, C39.2, C47.2, C62.2, J4.6 (GND), J4.9 (SW_DETECT), J4.11 (MP), J4.12 (MP), J4.13 (MP), J4.14 (MP), Q6.2 (S), Q8.2 (S), Q9.2 (S), Q11.2 (S), R81.2, R85.2, R86.2, R87.2, R88.2, R89.2, R90.2, R91.2, U11.4 (GND); also elsewhere on the board
unnamed: J4.2 (CD/DAT3), R96.2, R110.1
unnamed: J4.5 (CLK), R105.1
unnamed: J4.3 (CMD), R77.2, R109.1
unnamed: J4.7 (DAT0), R99.2, R113.1
unnamed: J4.8 (DAT1), R97.2, R112.1
unnamed: J4.1 (DAT2), R98.2, R111.1
unnamed: J7.2, Q6.3 (D), R41.1
unnamed: J9.2, Q8.3 (D), R46.1
unnamed: J10.2, Q11.3 (D), R44.1
unnamed: J11.2, Q9.3 (D), R43.1
unnamed: Q6.1 (G), R45.2, R91.1
unnamed: Q8.1 (G), R47.2, R88.1
unnamed: Q9.1 (G), R49.2, R90.1
unnamed: Q11.1 (G), R48.2, R89.1
unnamed: R35.2, R44.2, R86.1
unnamed: R36.2, R41.2, R81.1
unnamed: R37.2, R46.2, R87.1
unnamed: R38.2, R43.2, R85.1
unnamed: R74.1, U11.2 (DO/IO_{1})
unnamed: R62.2, R117.1, U11.1 (~CS)
unnamed: R61.2, U11.7 (~HOLD/~RESET/IO_{3})
Relay1: R47.1; also elsewhere on the board
Relay2: R48.1; also elsewhere on the board
Relay3: R45.1; also elsewhere on the board
Relay4: R49.1; also elsewhere on the board
SDIO_CDS: C28.1, J4.10 (SW_DETECT), R40.2; also elsewhere on the board
SDIO_CLK: R105.2; also elsewhere on the board
SDIO_CMD: R109.2; also elsewhere on the board
SDIO_D0: R113.2; also elsewhere on the board
SDIO_D1: R112.2; also elsewhere on the board
SDIO_D2: R111.2; also elsewhere on the board
SDIO_D3: R110.2; also elsewhere on the board

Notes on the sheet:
Relay-1
[3] Connections & Relays
Relay-3
MAX Current consumption ≈ 163mA
Flash Memory
Relay-4
SD-card
Relay-2

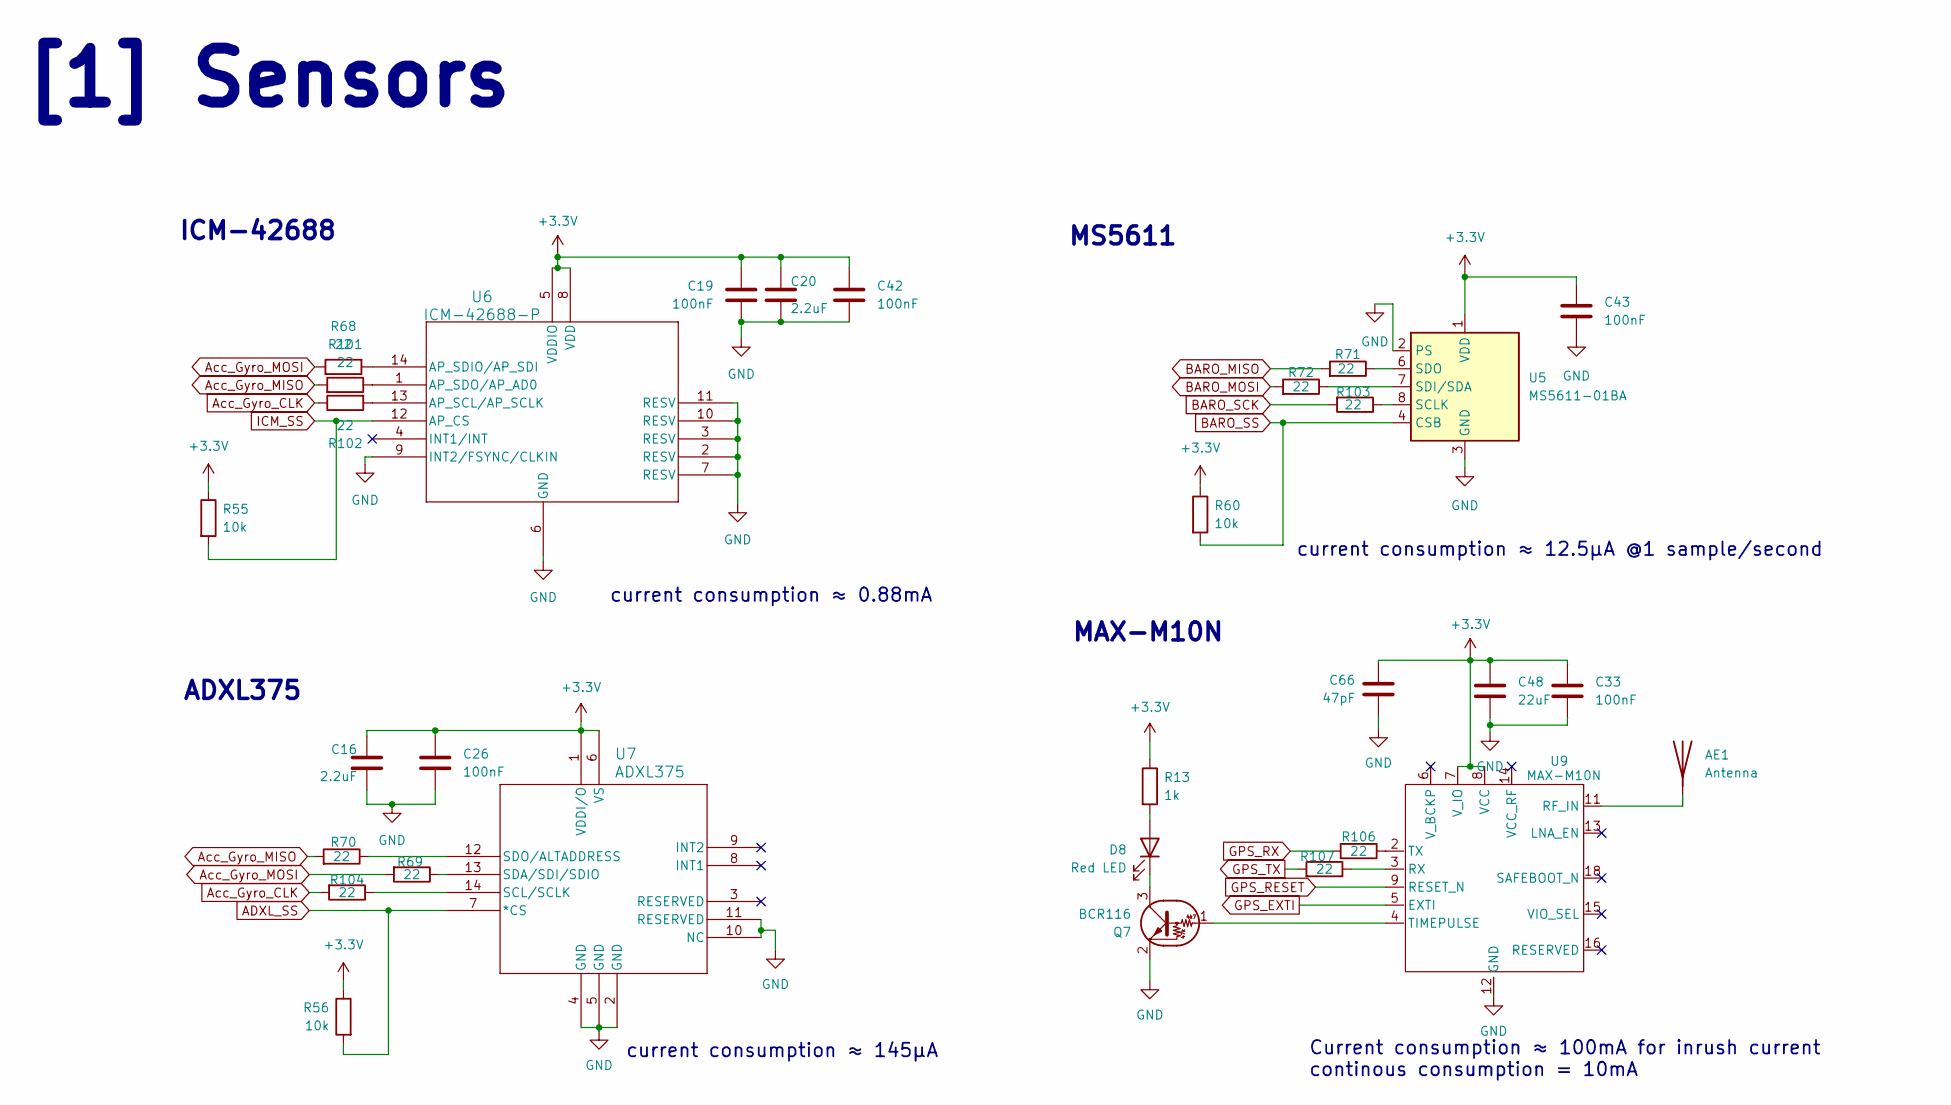
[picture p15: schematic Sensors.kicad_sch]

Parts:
AE1: Antenna; SMA_Amphenol_132134-10_Vertical
C16, C20: 2.2uF; C_0603_1608Metric; Part Number CL10B225KP8NNNC
C19, C26, C33, C42, C43: 100nF; C_0603_1608Metric; Part Number CL10B104KO8WPNC
C48: 22uF; C_0805_2012Metric; Part Number CL21A226KOQNNNE
C66: 47pF; C_0603_1608Metric; Part Number CL10C470JB81PNC
D8: Red LED; C_0603_1608Metric; Part Number 27-21/R6C-AP1Q2B/3C
Q7: BCR116; SOT-23-3; Part Number BCR116E6327HTSA1
R13: 1k; R_0603_1608Metric; Part Number CRCW06031K00JNTABC
R55, R56, R60: 10k; R_0603_1608Metric; Part Number CRT03J7E1002
R68, R69, R70, R71, R72, R101, R102, R103, R104, R106, R107: 22; R_0603_1608Metric; Part Number CQ03SAJ0220T5E
U5: MS5611-01BA; LGA-8_3x5mm_P1.25mm; Part Number MS561101BA03-50
U6: ICM-42688-P; LGA14_2P5X3X0P91_TDK; Part Number ICM-42688-P
U7: ADXL375; LGA_CC-14-1_ADI-L; Part Number ADXL375BCCZ-RL7
U9: MAX-M10N; ublox_MAX; Part Number MAX-M10N-00B

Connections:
+3.3V: C16.1, C19.1, C20.1, C26.1, C33.1, C42.1, C43.1, C48.1, C66.1, R13.1, R55.1, R56.1, R60.1, U5.1 (VDD), U6.5 (VDDIO), U6.8 (VDD), U7.1 (VDDI/O), U7.6 (VS), U9.7 (V_IO), U9.8 (VCC); also elsewhere on the board
/Sensors/Connector_feed: AE1.1, U9.11 (RF_IN); also elsewhere on the board
Acc_flash_CLK: R104.1, U7.14 (SCL/SCLK); also elsewhere on the board
Acc_flash_MOSI: R69.1, U7.13 (SDA/SDI/SDIO); also elsewhere on the board
BARO_icm_MOSI: R68.1, R72.1, U5.7 (SDI/SDA), U6.14 (AP_SDIO/AP_SDI); also elsewhere on the board
GND: C16.2, C19.2, C20.2, C26.2, C33.2, C42.2, C43.2, C48.2, C66.2, Q7.2 (E), U5.2 (PS), U5.3 (GND), U6.2 (RESV), U6.3 (RESV), U6.6 (GND), U6.7 (RESV), U6.9 (INT2/FSYNC/CLKIN), U6.10 (RESV), U6.11 (RESV), U7.2 (GND), U7.4 (GND), U7.5 (GND), U7.10 (NC), U7.11 (RESERVED), U9.1 (GND), U9.10 (GND), U9.12 (GND); also elsewhere on the board
GPS_RX: R106.2; also elsewhere on the board
GPS_TX: R107.2; also elsewhere on the board
unnamed: D8.2 (A), R13.2
unnamed: D8.1 (K), Q7.3 (C)
unnamed: Q7.1 (B), U9.4 (TIMEPULSE)
unnamed: R68.2, R69.2
unnamed 78: R60.2, U5.4 (CSB), U5.5 (CSB); also elsewhere on the board
unnamed: R71.1, U5.6 (SDO)
unnamed: R101.1, U6.1 (AP_SDO/AP_AD0)
unnamed 86: R56.2, U7.7 (*CS); also elsewhere on the board
unnamed: R70.1, U7.12 (SDO/ALTADDRESS)
unnamed 93: U9.5 (EXTI); also elsewhere on the board
unnamed 94: U9.9 (RESET_N); also elsewhere on the board
unnamed: R107.1, U9.3 (RX)
unnamed: R106.1, U9.2 (TX)

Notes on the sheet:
current consumption ≈ 12.5µA @1 sample/second
ICM-42688
[1] Sensors
MAX-M10N
current consumption ≈ 145µA
current consumption ≈ 0.88mA
MS5611
Current consumption ≈ 100mA for inrush current continous consumption = 10mA
ADXL375

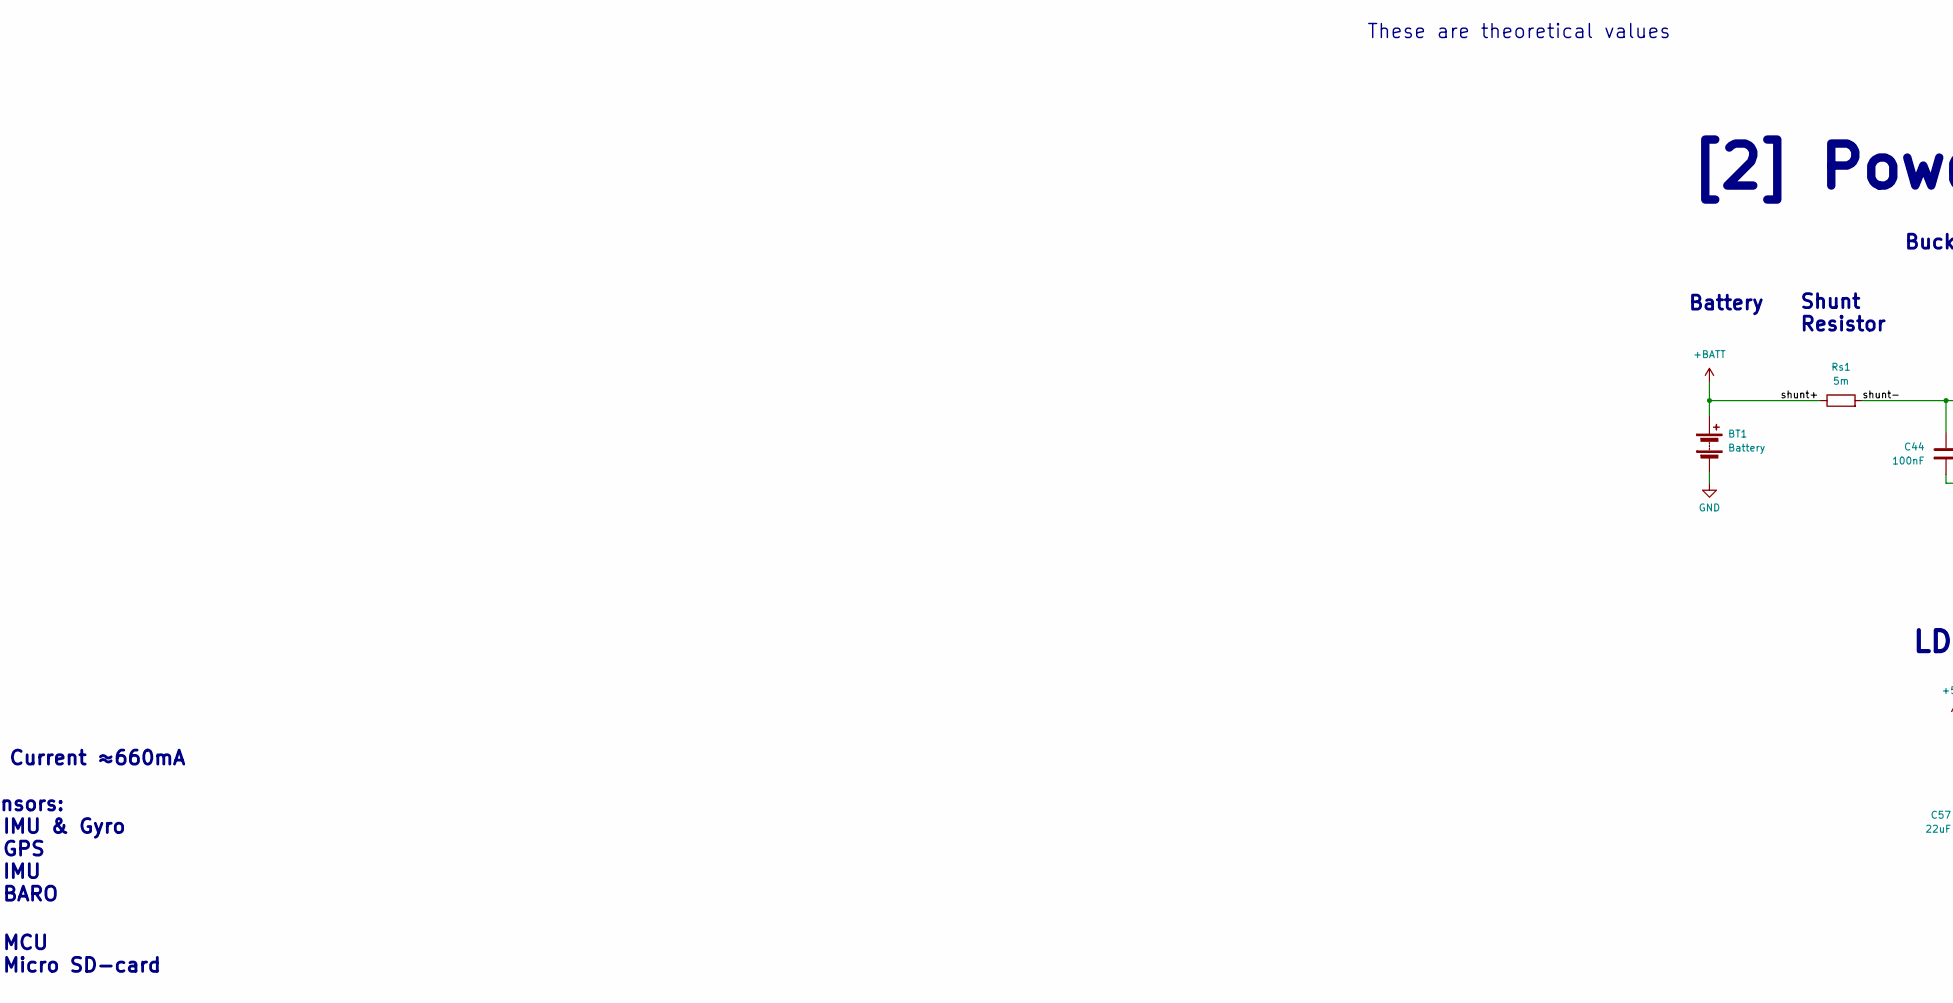
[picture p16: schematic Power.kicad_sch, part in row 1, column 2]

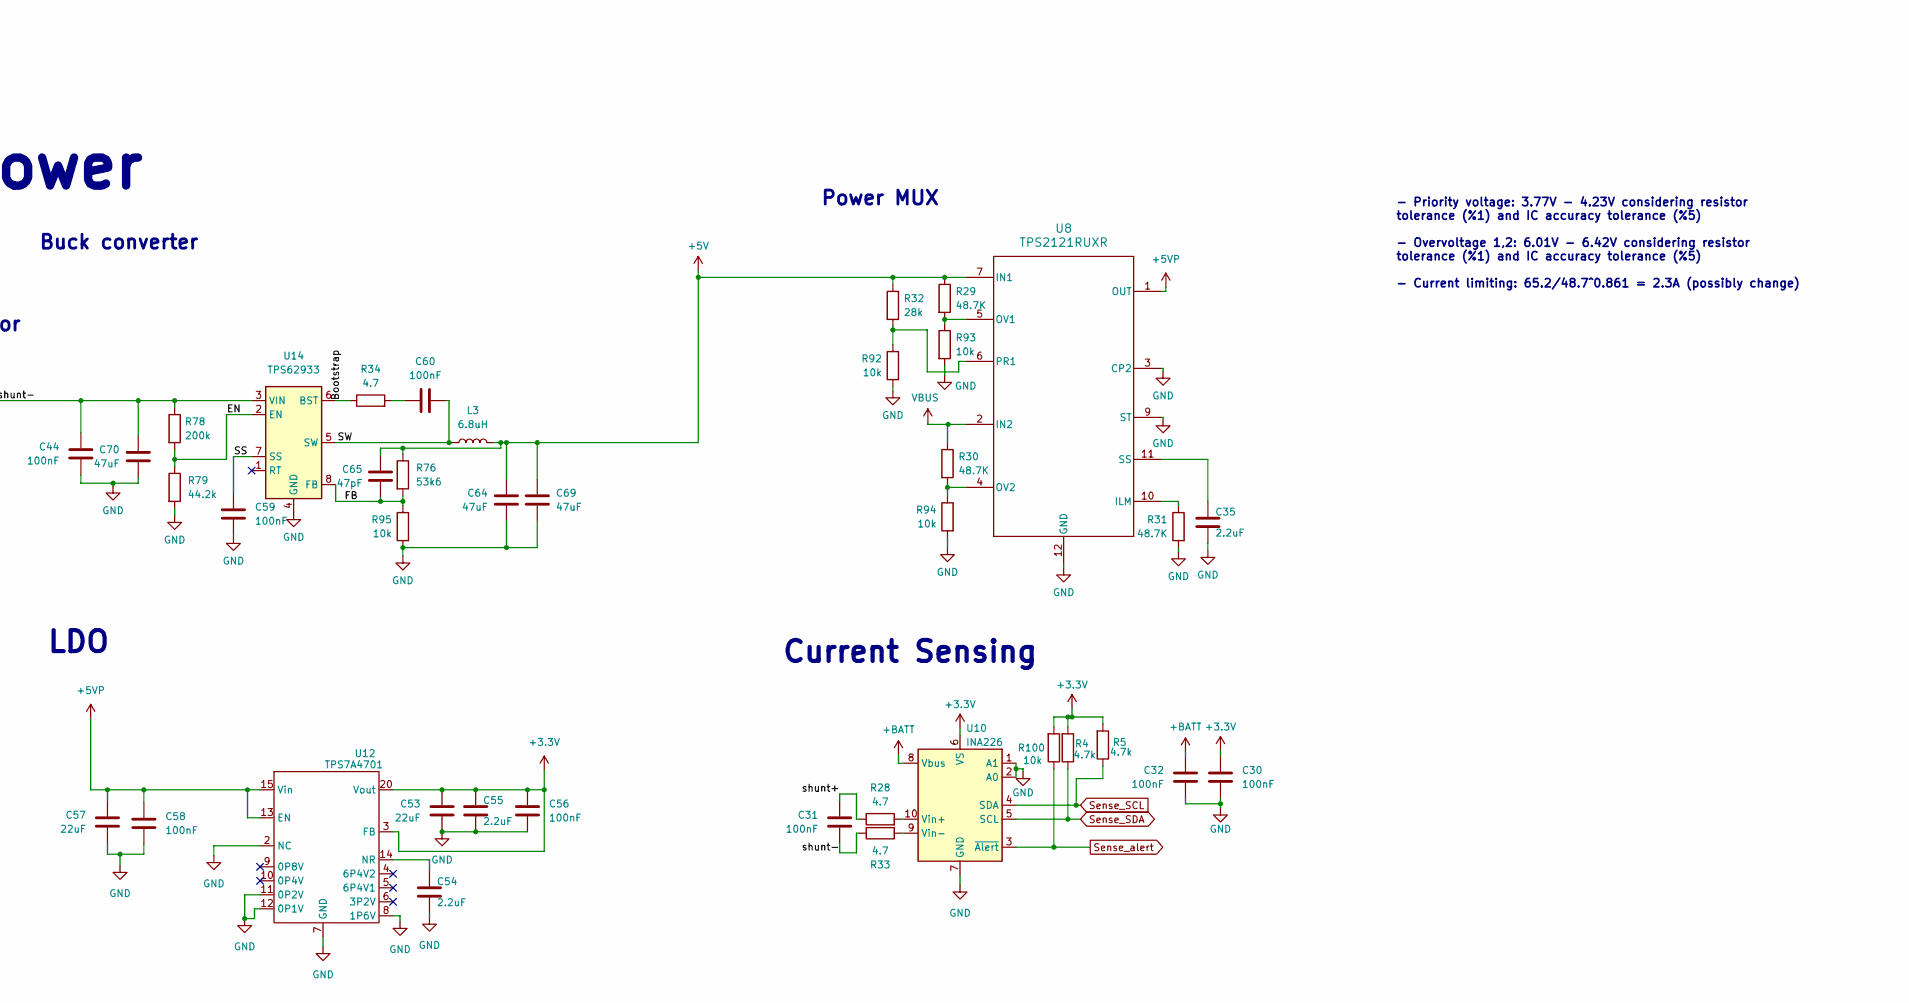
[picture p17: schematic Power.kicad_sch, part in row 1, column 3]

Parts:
BT1: Battery; AMASS_XT60-M_1x02_P7.20mm_Vertical; Part Number XT60
C30, C31, C32, C44, C56, C58, C59, C60: 100nF; C_0603_1608Metric; Part Number CL10B104KO8WPNC
C35, C54, C55: 2.2uF; C_0603_1608Metric; Part Number CL10B225KP8NNNC
C53, C57: 22uF; C_0805_2012Metric; Part Number CL21A226KOQNNNE
C64, C69, C70: 47uF; C_1210_3225Metric; Part Number CL32A476KOJNNNE
C65: 47pF; C_0603_1608Metric; Part Number CL10C470JB81PNC
L3: 6.8uH; L_Wuerth_XHMI-6060; Part Number 74439346068
R4, R5: 4.7k; R_0603_1608Metric; Part Number CQ03SAJ0472T5E
R28, R33, R34: 4.7; R_0603_1608Metric; Part Number CQ03SAF470KT5E
R29, R30, R31: 48.7K; R_0603_1608Metric; Part Number 0603SAF4872T5E
R32: 28k; R_0603_1608Metric; Part Number MCT06030C2802FP500
R76: 53k6; R_0603_1608Metric; Part Number RT0603BRD0753K6L
R78: 200k; R_0603_1608Metric; Part Number TC0325B2003T5C
R79: 44.2k; R_0603_1608Metric; Part Number RT0603FRE0744K2L
R92, R93, R94, R95: 10k; R_0603_1608Metric; Part Number TC0350B1002T5F
R100: 10k; R_0603_1608Metric; Part Number CRT03J7E1002
Rs1: 5m; R_1206_3216Metric; Part Number WSLP12065L000FEA
U8: TPS2121RUXR; RUX0012A; Part Number TPS2121RUXR
U10: INA226; TSSOP-10_3x3mm_P0.5mm; Part Number INA226AIDGSR
U12: TPS7A4701; Texas_RGW0020A_VQFN-20-1EP_5x5mm_P0.65mm_EP3.15x3.15mm; Part Number TPS7A4701
U14: TPS62933; SOT-583-8

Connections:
+3.3V: C30.1, C53.1, C55.1, C56.1, R4.2, R5.2, R100.2, U10.6 (VS), U12.1 (Vout), U12.3 (FB), U12.20 (Vout); also elsewhere on the board
+5V: C64.1, C65.1, C69.1, L3.2, R29.1, R32.1, R76.1, U8.7 (IN1); also elsewhere on the board
+5VP: C57.1, C58.1, U8.1 (OUT), U8.8 (OUT), U12.13 (EN), U12.15 (Vin), U12.16 (Vin); also elsewhere on the board
+BATT: BT1.1 (+), C31.1, C32.1, R28.1, Rs1.1, U10.8 (Vbus); also elsewhere on the board
/Power/Bootstrap: R34.1, U14.6 (BST)
/Power/EN: R78.2, R79.1, U14.2 (EN)
/Power/FB: C65.2, R76.2, R95.1, U14.8 (FB)
/Power/SS: C59.1, U14.7 (SS)
/Power/SW: C60.2, L3.1, U14.5 (SW)
/Power/shunt-: C31.2, C44.1, C70.1, R33.1, R78.1, Rs1.2, U14.3 (VIN)
GND: BT1.2 (-), C30.2, C32.2, C35.2, C44.2, C53.2, C54.2, C55.2, C56.2, C57.2, C58.2, C59.2, C64.2, C69.2, C70.2, R31.2, R79.2, R92.2, R93.2, R94.2, R95.2, U8.3 (CP2), U8.9 (ST), U8.12 (GND), U10.1 (A1), U10.2 (A0), U10.7 (GND), U12.2 (NC), U12.7 (GND), U12.8 (1P6V), U12.11 (0P2V), U12.12 (0P1V), U12.17 (NC), U12.18 (NC), U12.19 (NC), U12.21 (PAD), U14.4 (GND); also elsewhere on the board
unnamed: C60.1, R34.2
unnamed: R31.1, U8.10 (ILM)
unnamed: R29.2, R93.1, U8.5 (OV1)
unnamed: R30.2, R94.1, U8.4 (OV2)
unnamed: R32.2, R92.1, U8.6 (PR1)
unnamed: C35.1, U8.11 (SS)
unnamed: R28.2, U10.10 (Vin+)
unnamed: R33.2, U10.9 (Vin-)
unnamed: C54.1, U12.14 (NR)
Sense_SCL: R5.1, U10.4 (SDA); also elsewhere on the board
Sense_SDA: R4.1, U10.5 (SCL); also elsewhere on the board
Sense_alert: R100.1, U10.3 (~Alert); also elsewhere on the board
VBUS: R30.1, U8.2 (IN2); also elsewhere on the board

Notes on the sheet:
Power MUX
Battery
LDO
These are theoretical values
- MCU - Micro SD-card
MAX Current ≈660mA
3.3V
[2] Power
----->
Buck converter
Current Sensing
Shunt Resistor
Sensors: - IMU & Gyro - GPS - IMU - BARO
USB-c ------>
- Priority voltage: 3.77V - 4.23V considering resistor tolerance (%1) and IC accuracy tolerance (%5) - Overvoltage 1,2: 6.01V - 6.42V considering resistor tolerance (%1) and IC accuracy tolerance (%5) - Current limiting: 65.2/48.7^0.861 = 2.3A (possibly change)
2S 6-8.4V
Buck converter ----->
Power input ---->
Power MUX

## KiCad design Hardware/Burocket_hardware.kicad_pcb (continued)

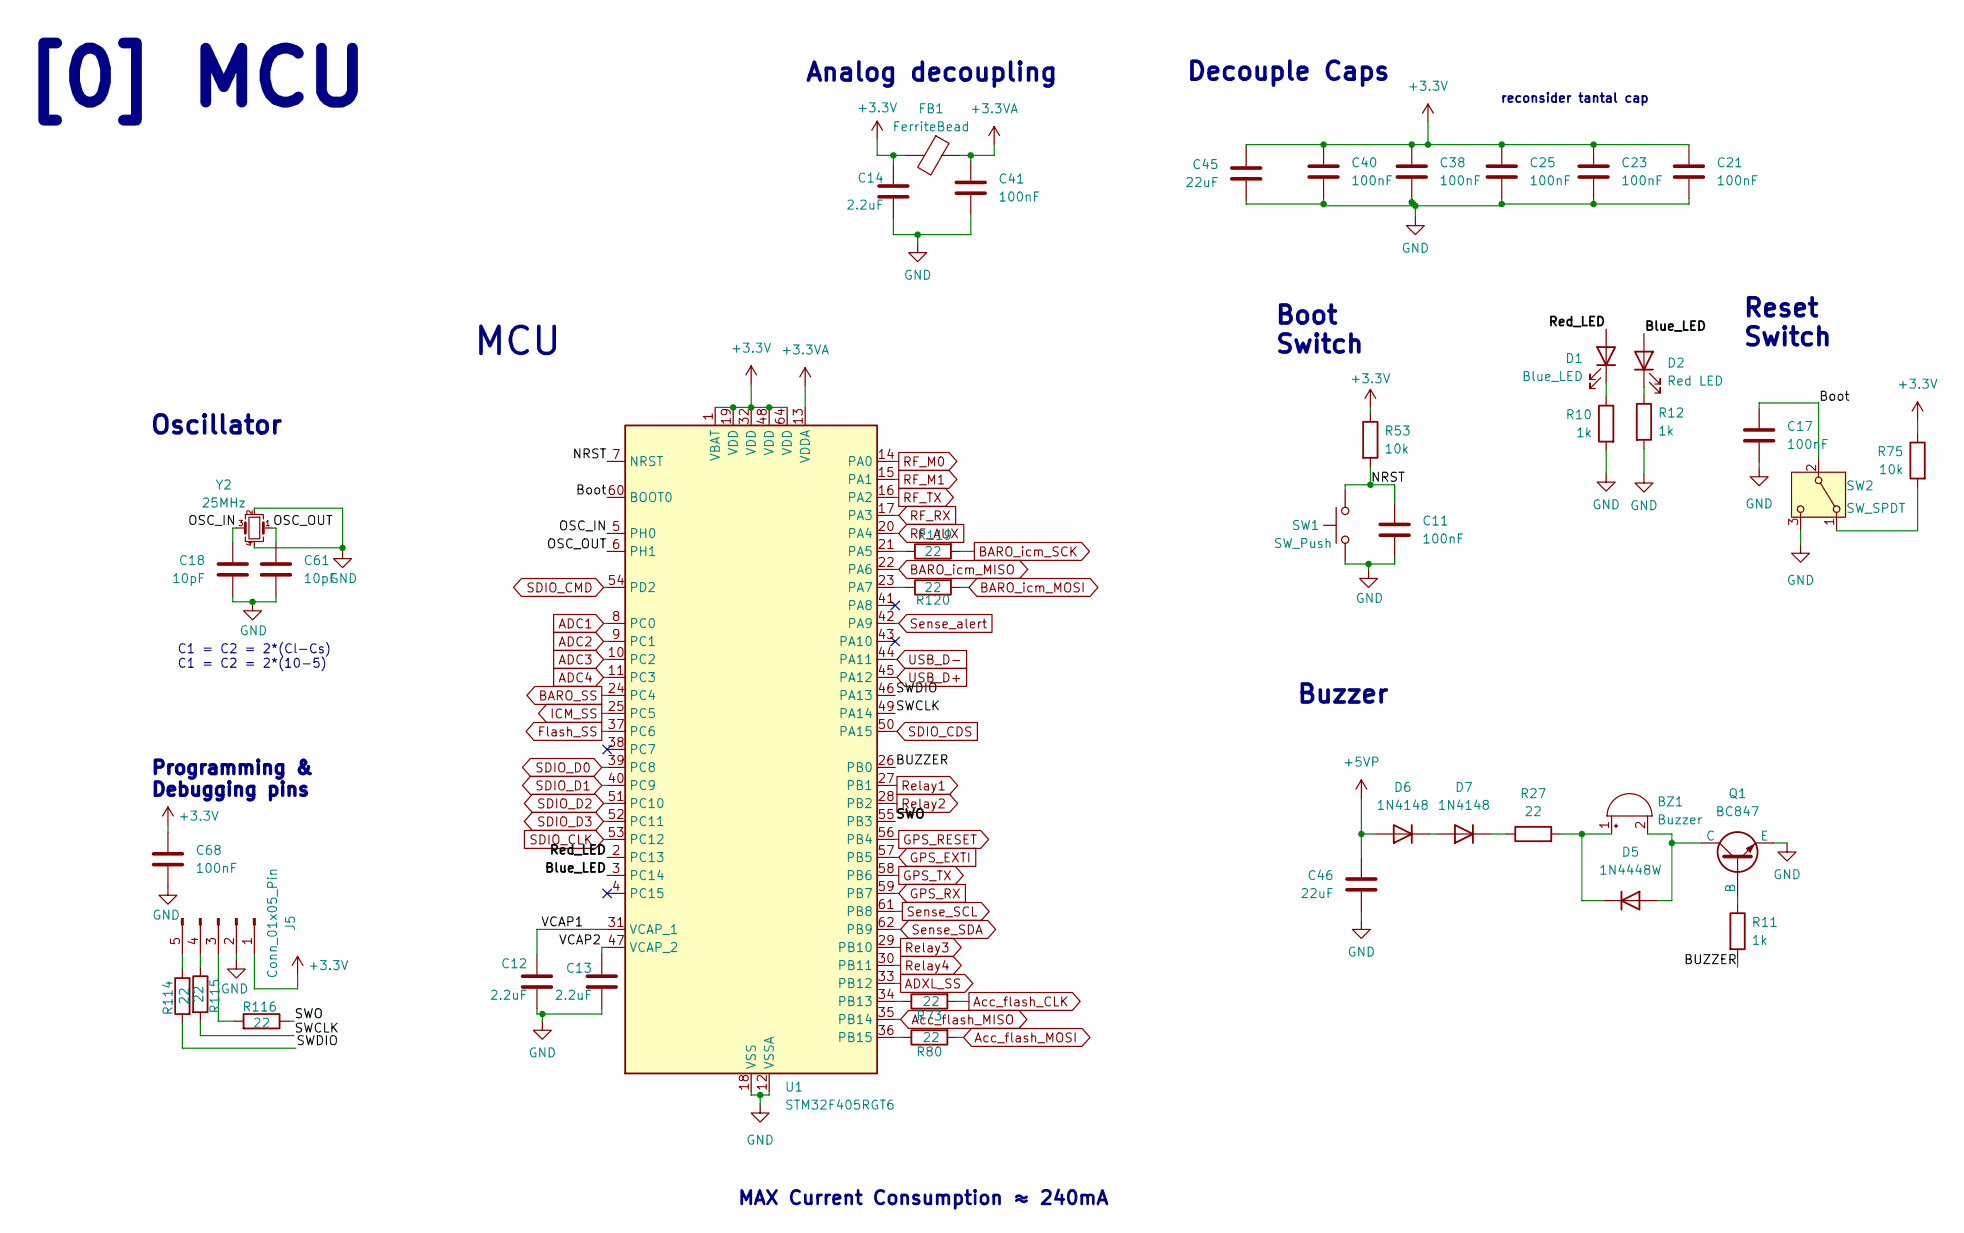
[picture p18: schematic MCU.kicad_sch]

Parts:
BZ1: Buzzer; Buzzer_typeshit; Part Number L-KLS3-SMT-3020-3V
C11, C17, C21, C23, C25, C38, C40, C41, C68: 100nF; C_0603_1608Metric; Part Number CL10B104KO8WPNC
C12, C13, C14: 2.2uF; C_0603_1608Metric; Part Number CL10B225KP8NNNC
C18, C61: 10pF; C_0603_1608Metric; Part Number CL10C100JB81PNC
C45, C46: 22uF; C_0805_2012Metric; Part Number CL21A226KOQNNNE
D1: Blue_LED; C_0603_1608Metric; Part Number HL-PST-1608H203BC
D2: Red LED; C_0603_1608Metric; Part Number 27-21/R6C-AP1Q2B/3C
D5: 1N4448W; Nexperia_CFP3_SOD-123W; Part Number 1N4448W_R1_00001
D6, D7: 1N4148; D_SOD-523; Part Number 1N4148WT
FB1: FerriteBead; R_0603_1608Metric; Part Number BLM18HE601SN1D
J5: Conn_01x05_Pin; PinHeader_1x05_P2.54mm_Vertical
Q1: BC847; SOT-323_SC-70; Part Number BC817-40W_R1_00001
R10, R11, R12: 1k; R_0603_1608Metric; Part Number CRCW06031K00JNTABC
R27: 22; R_0603_1608Metric; Part Number ERJPA3J220V
R53, R75: 10k; R_0603_1608Metric; Part Number CRT03J7E1002
R73, R80, R114, R115, R116, R119, R120: 22; R_0603_1608Metric; Part Number CQ03SAJ0220T5E
SW1: SW_Push; SW_SPST_PTS810; Part Number PTS815SJK250SMTRLFS
SW2: SW_SPDT; SW_SPDT_CK_JS102011SAQN; Part Number L-KLS7-MSK-12C03
U1: STM32F405RGT6; LQFP-64_10x10mm_P0.5mm
Y2: 25MHz; Crystal_SMD_2520-4Pin_2.5x2.0mm; Part Number ECS-250-10-36Q-ES-TR

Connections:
+3.3V: C14.1, C21.1, C23.1, C25.1, C38.1, C40.1, C45.1, C68.1, FB1.2, J5.1, R53.1, R75.1, U1.1 (VBAT), U1.19 (VDD), U1.32 (VDD), U1.48 (VDD), U1.64 (VDD); also elsewhere on the board
+3.3VA: C41.1, FB1.1, U1.13 (VDDA)
+5VP: C46.1, D6.2 (A); also elsewhere on the board
/MCU/BUZZER: R11.2, U1.26 (PB0)
/MCU/Blue_LED: D2.2 (A), U1.3 (PC14)
/MCU/Boot: C17.1, SW2.2 (B), U1.60 (BOOT0)
/MCU/NRST: C11.1, R53.2, SW1.2, U1.7 (NRST)
/MCU/OSC_IN: C18.1, U1.5 (PH0), Y2.3
/MCU/OSC_OUT: C61.1, U1.6 (PH1), Y2.1
/MCU/Red_LED: D1.2 (A), U1.2 (PC13)
/MCU/SWCLK: R115.2, U1.49 (PA14)
/MCU/SWDIO: R114.2, U1.46 (PA13)
/MCU/SWO: R116.1, U1.55 (PB3)
/MCU/VCAP1: C12.1, U1.31 (VCAP_1)
/MCU/VCAP2: C13.1, U1.47 (VCAP_2)
ADC1: U1.8 (PC0); also elsewhere on the board
ADC2: U1.9 (PC1); also elsewhere on the board
ADC3: U1.10 (PC2); also elsewhere on the board
ADC4: U1.11 (PC3); also elsewhere on the board
ADXL_SS: U1.33 (PB12); also elsewhere on the board
Acc_flash_CLK: R73.2; also elsewhere on the board
Acc_flash_MOSI: R80.2; also elsewhere on the board
BARO_SS: U1.24 (PC4); also elsewhere on the board
BARO_icm_MOSI: R120.2; also elsewhere on the board
Flash_SS: U1.37 (PC6); also elsewhere on the board
GND: C11.2, C12.2, C13.2, C14.2, C17.2, C18.2, C21.2, C23.2, C25.2, C38.2, C40.2, C41.2, C45.2, C46.2, C61.2, C68.2, J5.2, Q1.3 (E), R10.2, R12.2, SW1.1, SW2.3 (C), U1.12 (VSSA), U1.18 (VSS), U1.63 (VSS), Y2.2, Y2.4; also elsewhere on the board
GPS_EXTI: U1.57 (PB5); also elsewhere on the board
GPS_RESET: U1.56 (PB4); also elsewhere on the board
GPS_RX: U1.59 (PB7); also elsewhere on the board
GPS_TX: U1.58 (PB6); also elsewhere on the board
unnamed: BZ1.1 (+), D5.1 (K), R27.2
unnamed: BZ1.2 (-), D5.2 (A), Q1.1 (C)
unnamed: D1.1 (K), R10.1
unnamed: D2.1 (K), R12.1
unnamed: D6.1 (K), D7.2 (A)
unnamed: D7.1 (K), R27.1
unnamed: J5.3, R116.2
unnamed: J5.4, R115.1
unnamed: J5.5, R114.1
unnamed: Q1.2 (B), R11.1
unnamed: R75.2, SW2.1 (A)
unnamed: R119.1, U1.21 (PA5)
unnamed: R120.1, U1.23 (PA7)
unnamed: R73.1, U1.34 (PB13)
unnamed: R80.1, U1.36 (PB15)
RF_AUX: U1.20 (PA4); also elsewhere on the board
RF_M0: U1.14 (PA0); also elsewhere on the board
RF_M1: U1.15 (PA1); also elsewhere on the board
RF_RX: U1.17 (PA3); also elsewhere on the board
RF_TX: U1.16 (PA2); also elsewhere on the board
Relay1: U1.27 (PB1); also elsewhere on the board
Relay2: U1.28 (PB2); also elsewhere on the board
Relay3: U1.29 (PB10); also elsewhere on the board
Relay4: U1.30 (PB11); also elsewhere on the board
SDIO_CDS: U1.50 (PA15); also elsewhere on the board
SDIO_CLK: U1.53 (PC12); also elsewhere on the board
SDIO_CMD: U1.54 (PD2); also elsewhere on the board
SDIO_D0: U1.39 (PC8); also elsewhere on the board
SDIO_D1: U1.40 (PC9); also elsewhere on the board
SDIO_D2: U1.51 (PC10); also elsewhere on the board
SDIO_D3: U1.52 (PC11); also elsewhere on the board
Sense_SCL: U1.61 (PB8); also elsewhere on the board
Sense_SDA: U1.62 (PB9); also elsewhere on the board
Sense_alert: U1.42 (PA9); also elsewhere on the board
USB_D+: U1.45 (PA12); also elsewhere on the board
USB_D-: U1.44 (PA11); also elsewhere on the board

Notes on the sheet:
MCU
Reset Switch
Oscillator
Programming & Debugging pins
Decouple Caps
MAX Current Consumption ≈ 240mA
C1 = C2 = 2*(Cl-Cs) C1 = C2 = 2*(10-5)
Analog decoupling
Buzzer
Boot Switch
reconsider tantal cap
[0] MCU

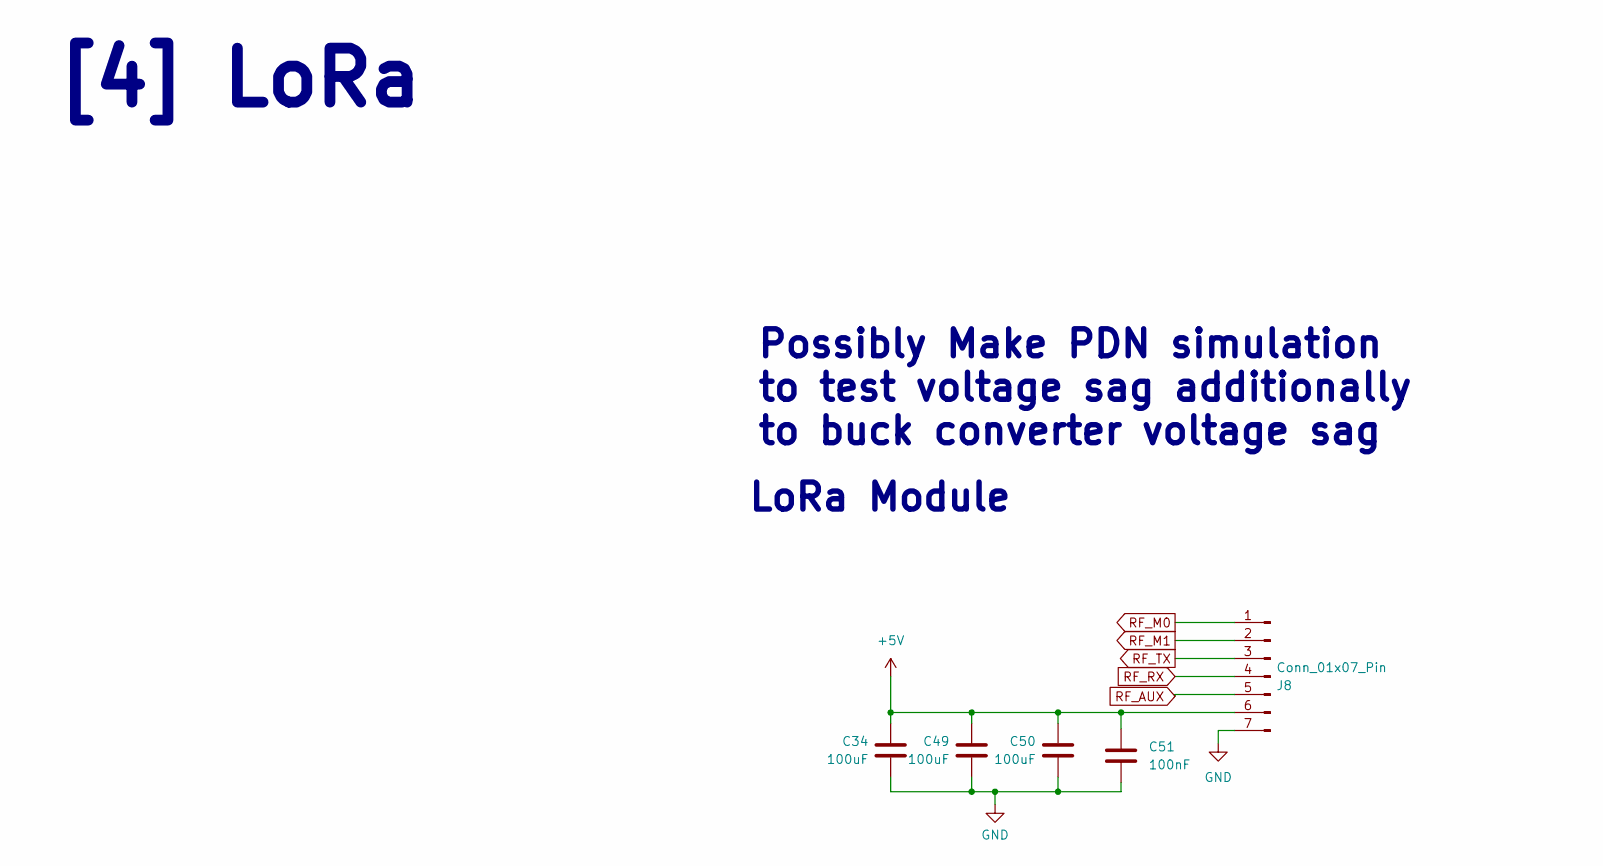
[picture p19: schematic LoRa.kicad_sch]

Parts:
C34, C49, C50: 100uF; CP_EIA-6032-20_AVX-F; Part Number 293D107X0010C2TE3
C51: 100nF; C_0603_1608Metric; Part Number CL10B104KO8WPNC
J8: Conn_01x07_Pin; E32-900T30D

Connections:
+5V: C34.1, C49.1, C50.1, C51.1, J8.6; also elsewhere on the board
GND: C34.2, C49.2, C50.2, C51.2, J8.7; also elsewhere on the board
unnamed 61: J8.3; also elsewhere on the board
unnamed 62: J8.4; also elsewhere on the board
unnamed 63: J8.5; also elsewhere on the board
RF_M0: J8.1; also elsewhere on the board
RF_M1: J8.2; also elsewhere on the board

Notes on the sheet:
Possibly Make PDN simulation to test voltage sag additionally to buck converter voltage sag
LoRa Module
[4] LoRa

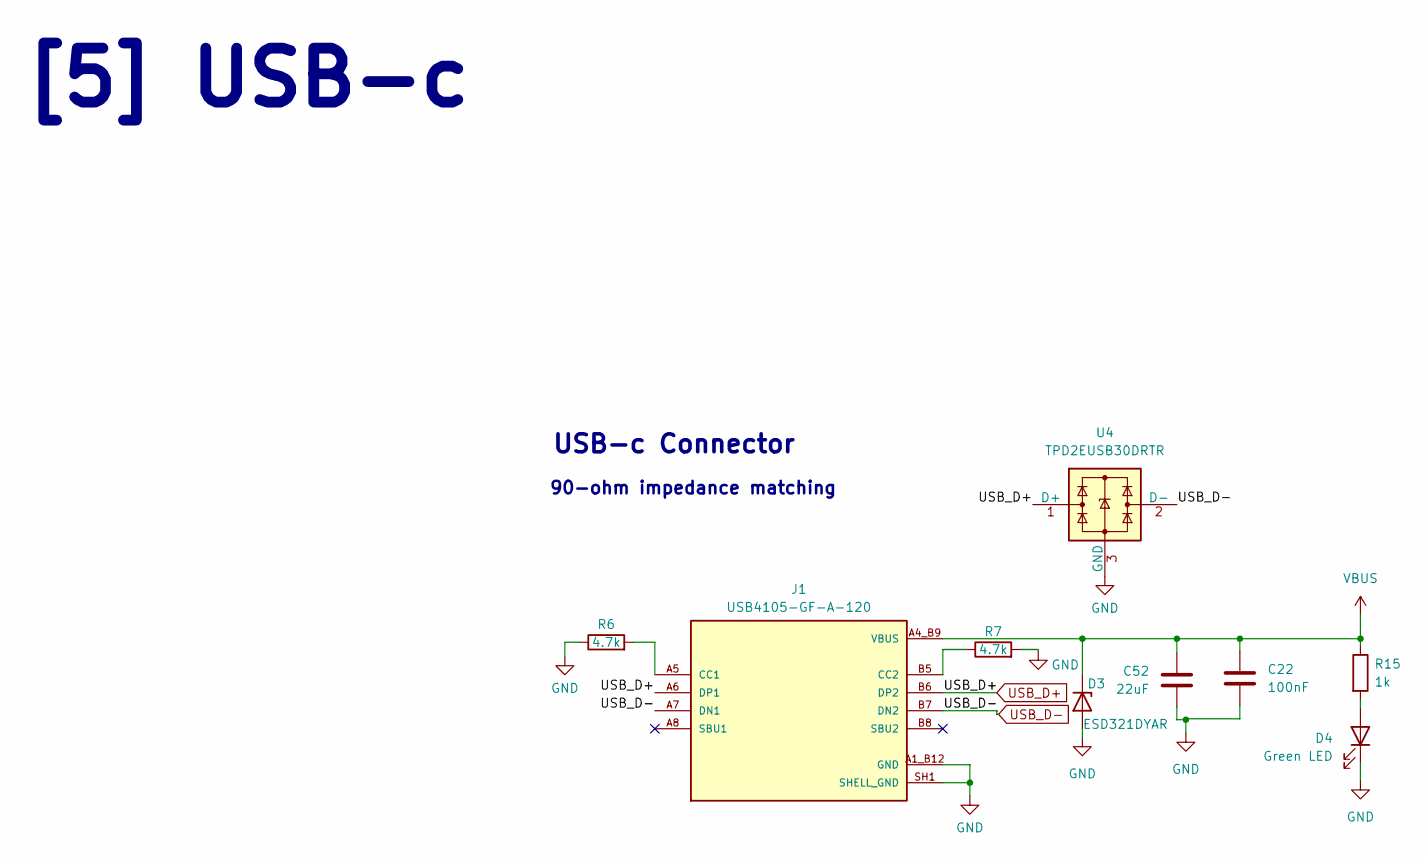
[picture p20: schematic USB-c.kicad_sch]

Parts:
C22: 100nF; C_0603_1608Metric; Part Number CL10B104KO8WPNC
C52: 22uF; C_0805_2012Metric; Part Number CL21A226KOQNNNE
D3: ESD321DYAR; D_SOD-523; Part Number ESD321DYAR
D4: Green LED; LED_0603_1608Metric; Part Number HL-PST-1608U51GC
J1: USB4105-GF-A-120; GCT_USB4105-GF-A-120; Part Number USB4105-GF-A-120
R6, R7: 4.7k; R_0603_1608Metric; Part Number CQ03SAJ0472T5E
R15: 1k; R_0603_1608Metric; Part Number CRCW06031K00JNTABC
U4: TPD2EUSB30DRTR; Texas_DRT-3; Part Number TPD2EUSB30DRTR

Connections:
GND: C22.2, C52.2, D3.2 (A), D4.1 (K), J1.A1_B12 (GND), J1.B1_A12 (GND), J1.SH1 (SHELL_GND), J1.SH2 (SHELL_GND), J1.SH3 (SHELL_GND), J1.SH4 (SHELL_GND), R6.1, R7.2, U4.3 (GND); also elsewhere on the board
unnamed: D4.2 (A), R15.2
unnamed 49: J1.A5 (CC1), R6.2; also elsewhere on the board
unnamed: J1.B5 (CC2), R7.1
USB_D+: J1.A6 (DP1), J1.B6 (DP2), U4.1 (D+); also elsewhere on the board
USB_D-: J1.A7 (DN1), J1.B7 (DN2), U4.2 (D-); also elsewhere on the board
VBUS: C22.1, C52.1, D3.1 (K), J1.A4_B9 (VBUS), J1.B4_A9 (VBUS), R15.1; also elsewhere on the board

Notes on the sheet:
USB-c Connector
[5] USB-c
90-ohm impedance matching

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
Board: 4 copper layers, 195 parts (54 on the bottom side), 129 nets, no tracks yet.

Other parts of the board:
C24: 2.2uF; C_0603_1608Metric
C63, C67: 100nF; C_0603_1608Metric
J2: Conn_Coaxial; SMA_Amphenol_132134-10_Vertical
R8: 5.1k; R_0603_1608Metric
R9, R14, R16: 220; R_0603_1608Metric
R17, R18: 4.7k; R_0603_1608Metric
R108, R118, R121, R122: 22; R_0603_1608Metric
TP1: TestPoint; Burocket Logo

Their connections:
+3.3V: C24.1, C63.1, C67.1, R17.2, R18.2; also elsewhere on the board
/Sensors/Connector_feed: J2.1 (In); also elsewhere on the board
ADXL_SS: R118.2; also elsewhere on the board
BARO_SS: R121.2; also elsewhere on the board
GND: C24.2, C63.2, C67.2, J2.2 (Ext), R8.1; also elsewhere on the board
GPS_EXTI: R16.1; also elsewhere on the board
GPS_RESET: R14.1; also elsewhere on the board
unnamed 49: R8.2; also elsewhere on the board
unnamed 61: R122.1; also elsewhere on the board
unnamed 62: R108.1; also elsewhere on the board
unnamed 63: R9.2; also elsewhere on the board
unnamed 78: R121.1; also elsewhere on the board
unnamed 86: R118.1; also elsewhere on the board
unnamed 93: R16.2; also elsewhere on the board
unnamed 94: R14.2; also elsewhere on the board
RF_AUX: R9.1; also elsewhere on the board
RF_M0: R17.1; also elsewhere on the board
RF_M1: R18.1; also elsewhere on the board
RF_RX: R108.2; also elsewhere on the board
RF_TX: R122.2; also elsewhere on the board

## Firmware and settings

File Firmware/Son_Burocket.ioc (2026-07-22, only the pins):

Mcu.UserName=STM32F405RGTx
PA0-WKUP.GPIO_Label=RF_M0
PA0-WKUP.Signal=GPIO_Output
PA1.GPIO_Label=RF_M1
PA1.Signal=GPIO_Output
PA11.Signal=USB_OTG_FS_DM
PA12.Signal=USB_OTG_FS_DP
PA13.Signal=SYS_JTMS-SWDIO
PA14.Signal=SYS_JTCK-SWCLK
PA15.GPIO_Label=SDIO_CDS
PA15.Signal=GPIO_Input
PA2.GPIO_Label=RF_TX
PA2.Signal=USART2_TX
PA3.GPIO_Label=RF_RX
PA3.Signal=USART2_RX
PA4.GPIO_Label=RF_AUX
PA4.Signal=GPXTI4
PA5.GPIO_Label=Baro_icm_SCK
PA5.Signal=SPI1_SCK
PA6.GPIO_Label=BARO_icm_MISO
PA6.Signal=SPI1_MISO
PA7.GPIO_Label=Baro_icm_MOSI
PA7.Signal=SPI1_MOSI
PA9.GPIO_Label=Sense_alert
PA9.Signal=GPXTI9
PB0.GPIO_Label=Buzzer
PB0.Signal=S_TIM3_CH3
PB1.GPIO_Label=Relay1
PB1.Signal=GPIO_Output
PB10.GPIO_Label=Relay3
PB10.Signal=GPIO_Output
PB11.GPIO_Label=Relay4
PB11.Signal=GPIO_Output
PB12.GPIO_Label=ADXL_SS
PB12.Signal=GPIO_Output
PB13.GPIO_Label=Acc_flash_SCK
PB13.Signal=SPI2_SCK
PB14.GPIO_Label=Acc_flash_MISO
PB14.Signal=SPI2_MISO
PB15.GPIO_Label=Acc_flash_MOSI
PB15.Signal=SPI2_MOSI
PB2.GPIO_Label=Relay2
PB2.Signal=GPIO_Output
PB3.Signal=SYS_JTDO-SWO
PB4.GPIO_Label=GPS_RESET
PB4.Signal=GPIO_Output
PB5.GPIO_Label=GPS_EXTI
PB5.Signal=GPIO_Input
PB6.GPIO_Label=GPS_TX
PB6.Signal=USART1_TX
PB7.GPIO_Label=GPS_RX
PB7.Signal=USART1_RX
PB8.GPIO_Label=Sense_SCL
PB8.Signal=I2C1_SCL
PB9.GPIO_Label=Sense_SDA
PB9.Signal=I2C1_SDA
PC0.GPIO_Label=ADC1
PC0.Signal=ADCx_IN10
PC1.GPIO_Label=ADC2
PC1.Signal=ADCx_IN11
PC10.Signal=SDIO_D2
PC11.Signal=SDIO_D3
PC12.Signal=SDIO_CK
PC13-ANTI_TAMP.GPIO_Label=Red_LED
PC13-ANTI_TAMP.Signal=GPIO_Output
PC14-OSC32_IN.GPIO_Label=Blue_LED
PC14-OSC32_IN.Signal=GPIO_Output
PC2.GPIO_Label=ADC3
PC2.Signal=ADCx_IN12
PC3.GPIO_Label=ADC4
PC3.Signal=ADCx_IN13
PC4.GPIO_Label=Baro_SS
PC4.Signal=GPIO_Output
PC5.GPIO_Label=ICM_SS
PC5.Signal=GPIO_Output
PC6.GPIO_Label=Flash_SS
PC6.Signal=GPIO_Output
PC8.Signal=SDIO_D0
PC9.Signal=SDIO_D1
PD2.Signal=SDIO_CMD
PH0-OSC_IN.Signal=RCC_OSC_IN
PH1-OSC_OUT.Signal=RCC_OSC_OUT

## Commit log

2026-07-07 Edited MCU page
    [Burocket_hardware.kicad_pcb, Burocket_hardware.kicad_sch, Connections_relays.kicad_sch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]
2026-07-08 Edited schematics
    [Burocket_hardware.kicad_sch, Connections_relays.kicad_sch, MCU.kicad_sch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]
2026-07-09 Selected components and added their properties, started the power schematics
    [Burocket_hardware.kicad_pcb, Connections_relays.kicad_sch, MCU.kicad_sch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]
2026-07-10 Added a simulations file, added App Notes file, Finalized SD-card design type shit
    [Burocket_hardware.kicad_sch, Connections_relays.kicad_sch, MCU.kicad_sch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]
2026-07-11 +1000 Aura
    [Burocket_hardware.kicad_sch, Connections_relays.kicad_sch, MCU.kicad_sch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]
2026-07-15 Only SSR and ferrite bead selection is left
    [Burocket_hardware.kicad_sch, Connections_relays.kicad_sch, LoRa.kicad_sch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]
2026-07-15 Changed some stupid mistake -100 Aura
    [Connections_relays.kicad_sch]
2026-07-16 Ne yazacagimi bilemedim
    [Burocket_hardware.kicad_pcb, Burocket_hardware.kicad_sch, Connections_relays.kicad_sch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]
2026-07-20 Updated schematics
    [Burocket_hardware.kicad_pcb, Power.kicad_sch, Sensors.kicad_sch]
2026-07-21 Commit bulamadim :)
    [Burocket_hardware.kicad_sch, Connections_relays.kicad_sch, LoRa.kicad_sch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]
2026-07-22 Added New file for additional resources used, Changed LDO for lower noise, changed buck converter for higher switching speed, smaller inductance value, better transient current response
    [Burocket_hardware.kicad_pcb, Burocket_hardware.kicad_sch, Connections_relays.kicad_sch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]
2026-07-23 Added Impedance matching calculations, finished buck converter calculations, finalized buzzer circuitry
    [Burocket_hardware.kicad_pcb, Burocket_hardware.kicad_sch, Connections_relays.kicad_sch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]
2026-07-25 Changed footprints, generated BOM
    [Burocket_hardware.csv, Burocket_hardware.kicad_sch, Connections_relays.kicad_sch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]
2026-07-25 Changed oscillator footprint
    [MCU.kicad_sch]
2026-07-25 Final changes
    [Connections_relays.kicad_sch, Power.kicad_sch]
2026-07-25 Final touches
    [Connections_relays.kicad_sch, Power.kicad_sch, Sensors.kicad_sch]
2026-07-27 Changed diff pair impedance calculation
    [MCU.kicad_sch]
2026-07-28 Updated BOM
    [Burocket_hardware.csv]
2026-07-29 Added Mosfet simulation file
2026-07-30 Added MOSFET simulation files with official spice model
    [Burocket_hardware.csv, Burocket_hardware.kicad_sch, MCU.kicad_sch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]
2026-08-09 Purged heavy binaries and updated gitignore
    [ADXL375BCCZ-RL.STEP, Burocket_hardware.csv, Burocket_hardware.kicad_pcb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]
